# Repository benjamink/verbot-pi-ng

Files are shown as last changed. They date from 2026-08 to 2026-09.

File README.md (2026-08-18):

# verbot-pi-ng

Control a 1984 [Tomy Verbot](https://www.theoldrobots.com/verbot.html) toy robot
from a Raspberry Pi Zero 2 W, over an HTTP API, with speech output.

The original 1980s electronics are removed; the motor, gearbox, interrogation
switch bank and front keypad are all retained and driven directly from the Pi.

New here? [**Theory of operation**](docs/theory-of-operation.md) explains how
the gearbox works, what replaced the original electronics, how the software
drives it, and the API.

## Status

**Software complete and tested off-Pi; not yet run on the robot.**

The state machine, HTTP API, speech, keypad and both hardware adapters are
implemented with a passing test suite that needs no Raspberry Pi. What remains
is physical bring-up: wiring the MCP23017 to the front panel, and working
through the [bring-up checklist](docs/deployment.md#bring-up-checklist) to
verify switch polarity, button order and the measured motor speeds.

See [the implementation plan](docs/superpowers/plans/2026-08-11-verbot-pi-ng.md)
for the task breakdown and deferred phase 2 work.

## Features

- **HTTP API** (FastAPI) for every robot action, with OpenAPI docs at `/docs`
- **Speech output** via an I2S DAC and `espeak-ng`
- **Front-panel keypad** — the original eight buttons drive the robot directly,
  with no network required
- **Status LED** in the original panel position
- **Optional shutdown endpoint** — power the Pi down over HTTP, guarded by a
  token and off by default
- **Zeroconf/mDNS** service advertisement for discovery
- **Runs its full test suite off-Pi** — hardware sits behind protocols with
  in-memory fakes

## Hardware

- Tomy Verbot with working motor and gearbox
- Raspberry Pi Zero 2 W (64-bit Raspberry Pi OS, Trixie)
- DRV8833 dual motor driver carrier
- MAX98357A I2S DAC/amplifier + small **passive** speaker (4–8Ω)
- MCP23017 I2C GPIO expander (front-panel buttons + status LED)
- [Pimoroni OnOff SHIM](https://shop.pimoroni.com/products/onoff-shim)
- 5V USB power bank

Wiring, pin assignments and the reverse-engineered mechanical details are in
[`docs/hardware.md`](docs/hardware.md), and the full schematic is at
[`hardware/verbot-schematic.pdf`](hardware/verbot-schematic.pdf)
([SVG](hardware/verbot-schematic.svg)). For bench work,
[`hardware/wiring-map.html`](hardware/wiring-map.html) draws the same wiring in
colour, with the interrogation ribbon in its actual conductor colours.

## Development

Requires [uv](https://docs.astral.sh/uv/). No Raspberry Pi needed — the
hardware layer has fakes.

```bash
uv sync            # create .venv and install deps
uv run pytest      # run the test suite
uv run ruff check  # lint
```

## Running on the Pi

```bash
sudo apt install espeak-ng
uv sync --extra pi --frozen
VERBOT_USE_REAL_HARDWARE=true uv run verbot
```

Full instructions, including the required device tree overlays and the
bring-up checklist, are in [`docs/deployment.md`](docs/deployment.md).

## Credits

The hardware reverse-engineering this project depends on was done by
**Neil Davis** for [neildavis/verbot-pi](https://github.com/neildavis/verbot-pi).
This is an independent rewrite targeting different hardware, without the Google
Assistant integration. See [LICENSE](LICENSE).

## License

MIT

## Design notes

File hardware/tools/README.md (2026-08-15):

# Schematic generator

One-shot scaffolding that produced `../verbot.kicad_sch`.

Writing a 40-pin header plus six module blocks as raw S-expressions by hand is
impractical — every coordinate must land on the 1.27mm grid, and the file must
embed a full copy of every symbol it uses. This generator reads the geometry
out of the KiCad libraries so those numbers are derived rather than typed.

**The generated `.kicad_sch` is authoritative.** Once it has been opened and
edited in eeschema, do not re-run the generator over it — you would discard
those edits. It is kept here because it documents how the sheet was built and
would save real work if the pin map ever changed wholesale.

`selftest.py` is a standalone script, not a pytest module, even though the
rest of the repo uses pytest exclusively. Its checks read
`/usr/share/kicad/symbols`, which only exists on a machine with KiCad
installed; folding it into `tests/` would break the README's promise that
`uv run pytest` works on any machine with no special setup.

```bash
cd hardware/tools
python3 selftest.py            # check the geometry reader
python3 generate_schematic.py  # regenerate (destructive)
```

If you regenerate `verbot.kicad_sym` with `make_symbols.py`, run
`kicad-cli sym upgrade --force ../verbot.kicad_sym` afterwards. `make_symbols.py`
writes each pin's `(at ...)` on the same line as `(pin ...)`; `_PIN_RE` in
`kicadgen.py` requires the newline-before-`(at` layout that only the upgrade
pass produces, and without it `generate_schematic.py` fails with `KeyError:
'1'` trying to look up a pin number that was never parsed.

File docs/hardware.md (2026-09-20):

# Verbot Hardware Reference

> **Attribution:** The electro-mechanical analysis and the interrogation switch
> wiring table in this document were reverse-engineered by **Neil Davis** for
> [neildavis/verbot-pi](https://github.com/neildavis/verbot-pi) (MIT licensed),
> partly from [Tomy's patent US4717364A](https://patents.google.com/patent/US4717364A/en).
> They are reproduced here with thanks. The GPIO assignments are new to this
> project and differ from the original.

> 📐 **Schematic:** [`hardware/verbot-schematic.pdf`](../hardware/verbot-schematic.pdf)
> ([SVG](../hardware/verbot-schematic.svg)) — the full wiring on one sheet.
> Source: [`hardware/verbot.kicad_sch`](../hardware/verbot.kicad_sch) (KiCad 10).
> The GPIO table below and `src/verbot/config.py` remain the pin-map source of
> truth; the schematic reproduces them.

> 🎨 **Wiring map:** [`hardware/wiring-map.html`](../hardware/wiring-map.html)
> — the same wiring drawn in colour, with the interrogation ribbon rendered in
> its actual conductor colours. Easier to work from at the bench than the
> schematic; open it in a browser.

## Electro-mechanical operation

Verbot is driven by a **single bi-directional 3V DC motor** and a set of
planetary gears. Motor direction selects between two mutually exclusive modes:

| Polarity | Motor direction | Operating mode |
|---|---|---|
| Normal | Anti-clockwise  | Interrogation  |
| Reverse  | Clockwise | Action |

### Interrogation mode

The default on power-up. The motor turns a drum carrying 8 cams spaced equally
around its circumference. Each cam activates and then releases one of 8
normally-open switches in a fixed repeating sequence. Verbot performs no
visible movement in this mode — it is selecting which gear set is engaged.

The switches complete a circuit to ground, so their state is readable from
GPIO inputs.

### Action mode

Reversing the motor engages a clutch: the drum stops, leaving the last-selected
switch engaged, and a shaft inside the drum begins to turn. The planetary gear
set at the selected position performs its action, and continues until the motor
is reversed again.

The arm actions (`pick_up` / `put_down`) have mechanical **limit switches** in
series. When an arm reaches its travel limit the circuit breaks, which the
controller observes as the switch *releasing* while the action is running. That
is the signal to stop — without it the mechanism will strain against its stop.

### Putting it together

To perform action X: run the motor anti-clockwise until switch X activates,
then immediately reverse to clockwise. The gear set for X is now engaged and in
the correct position.

## Interrogation switch wiring

Nine-core ribbon cable from the gearbox switch bank to the original controller
board:

| Colour | Interrogation order | Action |
|---|---|---|
| White  | N/A | GND — common return for all switches |
| Purple | 1 | Stop |
| Red | 2 | Rotate right  |
| Yellow | 3 | Rotate left |
| Grey | 4 | Move forward  |
| Blue | 5 | Move backward |
| Brown  | 6 | Arms down / put down |
| Orange | 7 | Arms up / pick up |
| Green  | 8 | Talk |

## Power supply

- **3V DC** (orange +ve, black ground) from 2× 'C' cells drove the motor. The
  original board reversed its polarity; the DRV8833 does that job now.
- **6V DC** (red +ve, black ground) from 4× 'AA' cells fed the original control
  board. That board and supply are removed; a 5V USB power bank feeds the Pi.
- Both rails were switched by the board behind the front keypad panel, which
  also fed the red power LED in the panel's bottom-right corner.

Where the motor's supply comes from now, and why it is not the Pi, is in
[Powering the motor](#powering-the-motor).

> ⚠️ The eight front-panel keypad buttons share that board with the power
> switching. Before wiring them to the MCP23017, trace whether they are
> independent switches to a common rail or a matrix, and decide what takes over
> the power-switch role (most likely the OnOff SHIM alone). It may be cleanest
> to bypass the original PCB and solder to the switch contacts directly.

## Original keypad behaviour

Each of the eight red buttons corresponded 1:1 to one of the eight actions. In
the original toy you *held a button down while speaking* the command you wanted
associated with it, and an LED blinked during program mode. This project
re-uses the 1:1 mapping; the hold gesture is available for re-binding.

## GPIO assignments (this project)

Raspberry Pi Zero 2 W, 64-bit Raspberry Pi OS (Trixie). **Bold** = Verbot
interrogation switches, inputs with pull-ups, active low.

| BCM | Physical | Used by | Function |
|-----|---|---|---|
| 2 | 3 | I2C1 | SDA — MCP23017 |
| 3 | 5 | I2C1 | SCL — MCP23017 |
| 4 | 7 | OnOff SHIM | Shutdown |
| 6 | 31 | DRV8833 | nSLEEP (`EEP`) — high wakes the driver (output) |
| 7 | 26 | **Verbot** | SW Talk |
| 8 | 24 | **Verbot** | SW Pick up |
| 9 | 21 | **Verbot** | SW Forwards |
| 10  | 19 | **Verbot** | SW Rotate left |
| 11  | 23 | **Verbot** | SW Put down |
| 12  | 32 | DRV8833 | Motor `IN1` — kernel PWM0 |
| 13  | 33 | DRV8833 | Motor `IN2` — kernel PWM1 |
| 16  | 36 | DRV8833 | nFAULT (`ULT`) — active low, input with pull-up |
| 17  | 11 | **Verbot** | Ready signal — high once the API is serving (output). Reassigned from the OnOff SHIM's power button; this board has no SHIM fitted. If one is added later, move this to a free pin instead. |
| 18  | 12 | I2S DAC | BCLK |
| 19  | 35 | I2S DAC | LRCLK |
| 21  | 40 | I2S DAC | DIN |
| 22  | 15 | **Verbot** | SW Stop |
| 25  | 22 | **Verbot** | SW Reverse |
| 26  | 37 | **Verbot** | SW Rotate right |
| 27  | 13 | OnOff SHIM | LED |

Both PWM channels come from one overlay:
`dtoverlay=pwm-2chan,pin=12,func=4,pin2=13,func2=4`.

**Free:** BCM 5, 14, 15, 20, 23, 24.

### Count the I2S pins twice

The three I2S lines sit next to pins that fail silently when you are off by one:

| Intended | Header | Neighbour | What you get |
|---|---|---|---|
| BCLK | 12 | **14 = GND** | Bit clock grounded. Dead silence. |
| DIN | 40 | **38 = BCM 20, PCM_DIN** | Data on the input pin. Dead silence. |
| LRCLK | 35 | 33 = BCM 13 (`IN2`) | Word clock into the motor driver. |

None of these produce an error anywhere. The overlay still registers the card,
`aplay -l` still lists the MAX98357A, `pinctrl get 18-21` still reports `a0` on
all three, and `/proc/asound/card0/pcm0p/sub0/hw_params` still reads `RUNNING`
with the pointer advancing. The Pi is genuinely clocking valid I2S — it is just
not arriving. Every software check passes while the speaker stays silent.

If there is no sound, check continuity from the header pin to the breakout pad
**before** touching the overlay. `speaker-test -D plughw:0,0` returning 0 says
nothing about whether audio reached the amp.

Confirm the amp is alive with a meter instead: SD_MODE on the Adafruit board
sits at ~0.45 V (its 1 MΩ pull-up against the chip's 100 kΩ internal pulldown),
which the MAX98357A reads as enabled in (L+R)/2 mono. Below 0.16 V is shutdown.
That reading also means `no-sdmode` is correct for this board — SD_MODE is not
wired to a GPIO, so the `sdmode` overlay variant does nothing here except claim
BCM 4, which the OnOff SHIM needs.

## DRV8833 carrier wiring

The common 12-pin breakout (`IN1`–`IN4`, `OUT1`–`OUT4`, `VCC`, `GND`, `EEP`,
`ULT`). Only channel A is used; `IN3`/`IN4`/`OUT3`/`OUT4` are left unconnected.

| Carrier pin | Goes to | Notes |
|---|---|---|
| `VCC` | Motor supply | **Not a logic rail.** The chip runs its own 3.3V regulator off this, so whatever you apply is what the motor sees. |
| `GND` | Pi GND | Common ground with the Pi is required for the logic to work. |
| `IN1` | BCM 12 | PWM0 |
| `IN2` | BCM 13 | PWM1 |
| `OUT1`/`OUT2` | Verbot motor | Polarity decides which sign is interrogation; swap if reversed. |
| `EEP` | BCM 6 | nSLEEP. The `J1` solder jumper ties this to `VCC` — check it with a meter. If it is bridged, set `VERBOT_MOTOR_SLEEP_PIN` to `null` and leave BCM 6 free. |
| `ULT` | BCM 16 | nFAULT, open-drain. Relies on the Pi's internal pull-up. |

Feeding `VCC` from 5V means the 3V motor sees 5V at full duty — cap
`VERBOT_ACTION_SPEED` accordingly rather than running it at ±100. Do **not**
feed `VCC` from the Pi's 3V3 pin to get a nominal 3V: that rail comes off the
PMIC and cannot supply a stalled motor.

There is no MODE pin. Unlike the DRV8835 this part has no PHASE/ENABLE mode,
which is why direction costs a second PWM channel rather than one GPIO.

### Powering the motor

**The Pi does not power the motor.** Two separate paths run through the carrier,
and confusing them is the usual source of "a GPIO can't supply that much
current":

- **Signal path** — `IN1`, `IN2` and `EEP` are high-impedance CMOS inputs
  drawing microamps. The Pi only says *which switches to close*. A GPIO sources
  around 16 mA, and the whole header perhaps 50 mA — orders of magnitude short
  of motor current, and it never has to supply it.
- **Power path** — motor current flows from `VCC`, through the H-bridge
  MOSFETs, out `OUT1`/`OUT2`, through the motor and back to `GND`. It never
  touches a GPIO.

That is why `VCC` is not a logic rail, and why the common ground still matters:
almost no current flows on that wire, but without a shared reference the carrier
cannot interpret the Pi's logic levels at all.

**Feed `VCC` from the power bank directly, not from the Pi's 5V header pin.**
The header pin is the USB input rail passed straight through, so it does work
electrically. But the motor then shares a supply with the Pi, and a stall or a
direction reversal can drag that rail down far enough to drop the Wi-Fi or reset
the board — and if the OnOff SHIM is inline, the motor current runs through the
SHIM as well. A 3V motor from 2× 'C' cells can pull on the order of an amp
stalled, which is not something to route through header pins.

Fit **100–470 µF** of electrolytic bulk capacitance across `VCC`/`GND` close to
the carrier. A direction reversal switches the full motor current in one step,
and without local storage that transient is taken straight out of the shared
supply.

| Pin | Feed from | Why |
|-----|---|-----|
| `VCC` | Power bank 5V | Not the Pi's 3V3 — that rail is off the PMIC and cannot supply a stalled motor |
| `GND` | Common with the Pi | Shared reference for the logic; carries no significant current |

Because `VCC` is 5V and the motor is a 3V part, cap `VERBOT_ACTION_SPEED` rather
than running ±100 — the PWM duty cycle is what keeps the average voltage near
the motor's rating.

### Notable changes from the original project

- **DRV8833 instead of a DRV8835**, driven as IN/IN on two kernel PWM channels
  (BCM 12 and 13) rather than one PWM plus a direction pin. Its `nSLEEP` and
  `nFAULT` lines are wired up; nothing reads the fault line yet.
- **Motor PWM is kernel-managed**, not pigpio. pigpio needs the PCM peripheral
  for DMA timing to leave hardware PWM available; the I2S DAC needs PCM too.
  Kernel PWM sidesteps that conflict entirely — the original project had to
  abandon hardware PWM for exactly this reason.
- **No AIY Voice Bonnet**, freeing BCM 14, 15, 16, 20, 23.
- Front-panel buttons and status LED hang off an **MCP23017** rather than
  consuming the last eight free GPIOs.

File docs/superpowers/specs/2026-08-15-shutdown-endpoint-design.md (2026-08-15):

# Token-guarded shutdown endpoint — design

**Date:** 2026-08-15
**Status:** approved, ready for implementation

## Goal

Let the robot be powered down cleanly over HTTP, so the Pi can be shut down
without SSH and without the Pimoroni OnOff SHIM.

## Why

The OnOff SHIM provides the soft power switch. It has not arrived yet, and
pulling USB power without a clean shutdown risks SD card corruption. `POST
/stop` sounds like it would help but does not — it runs a mechanical
interrogation to find the stop cam and has nothing to do with system power.

This endpoint stays useful after the SHIM is wired (shutting down from a phone
without walking to the robot), but it is deliberately small: the SHIM is the
real answer, and this should not grow into a general remote-administration
surface.

## Security context

The API has **no authentication**, binds `0.0.0.0:8080`, and advertises itself
over mDNS. Anything on the LAN can discover the robot and drive it. That is an
accepted trade-off for the existing endpoints, where the worst case is someone
waving the robot's arms.

Remote poweroff is a different proposition, so this endpoint is opt-in and
separately authenticated rather than inheriting the open surface.

## Deliverables

| File | Change |
|---|---|
| `src/verbot/config.py` | add `shutdown_token: str \| None = None` |
| `src/verbot/hardware/protocols.py` | add `SystemPower` protocol |
| `src/verbot/hardware/system_power.py` | new — `SubprocessPower` adapter |
| `src/verbot/hardware/fakes.py` | add `FakePower` |
| `src/verbot/main_support.py` | add `build_power(settings)` |
| `src/verbot/controller.py` | add `Controller.halt()` |
| `src/verbot/api.py` | widen `create_app`, add the route |
| `src/verbot/__main__.py` | pass `settings` and `power` to `create_app` |
| `tests/test_api.py` | update fixture, add endpoint tests |
| `tests/test_controller.py` | add `halt()` test |
| `tests/test_main.py` | add `build_power` test |
| `docs/deployment.md` | sudoers rule, token generation, caveats |
| `README.md` | one line in Features |

## The off switch

`Settings` gains:

```python
shutdown_token: str | None = None
```

When it is `None`, **the route is never registered**. Not registered-then-403:
genuinely absent, so it is also missing from `/docs` and `/openapi.json` and
the capability is not advertised to anyone scanning. The existing API surface
is byte-identical unless the operator opts in.

## SystemPower protocol

Follows the established `MotorDriver` / `SpeechEngine` / `Keypad` pattern, so
the suite keeps running off-Pi with no hardware and no root.

```python
# protocols.py
class SystemPower(Protocol):
    async def shutdown(self) -> None:
        """Power the machine off. Returns once the request is issued."""
```

`hardware/system_power.py` holds `SubprocessPower`, which shells out via
`asyncio.create_subprocess_exec`, mirroring how `EspeakEngine` already invokes
`espeak-ng`. `fakes.py` holds `FakePower`, which records `shutdown_called`.

`main_support.build_power(settings)` mirrors `build_hardware` and
`build_keypad`: **it returns `FakePower` whenever `use_real_hardware` is
false.** This is a safety property, not a convenience one — without it, running
the dev server on a laptop with a token configured would power off the laptop.

## The endpoint

```
POST /system/shutdown
  X-Verbot-Token: <token>

  202 { "status": "shutting down" }
  401 missing or incorrect token
  404 endpoint not configured
```

- The token is compared with `secrets.compare_digest`, so comparison is
  constant-time. A missing header short-circuits to a failure rather than being
  passed to `compare_digest`, which rejects `None`.
- On success the handler halts the motor, then schedules the poweroff as a
  FastAPI `BackgroundTask` so the 202 reaches the client before the machine
  dies.
- Returns 202 rather than 200: the shutdown has been accepted, not completed.

### Wiring

`create_app` widens to take the two new dependencies explicitly, rather than
reaching for globals:

```python
def create_app(
    controller: Controller,
    speech: SpeechEngine,
    settings: Settings,
    power: SystemPower,
) -> FastAPI:
```

Both new parameters are required. There are only two call sites —
`src/verbot/__main__.py:49` and the `client_rig` fixture in
`tests/test_api.py:16` — so widening is cheap, and a default would let a caller
silently get an app with no shutdown route when they meant to configure one.

`build_app` calls `build_power(settings)` alongside the existing
`build_hardware` and `build_keypad`, and passes both `settings` and `power`
through.

### Controller.halt()

A new method — cancel the pending timeout, then `set_speed_percent(0)`.

Strictly this is redundant: `poweroff` causes systemd to SIGTERM the unit,
which runs the FastAPI lifespan teardown, which already calls
`controller.close()` and stops the motor. Two reasons to do it explicitly
anyway:

1. That teardown is a few hundred milliseconds away, and the robot is driving
   for all of them.
2. If the sudoers rule is missing or wrong, `poweroff` fails silently and the
   motor would otherwise keep running indefinitely.

"Shutdown stops the robot" is the least surprising behaviour.

This is **not** `Action.STOP`. That runs a mechanical interrogation to find the
stop cam — the opposite of what is wanted when powering down.

## Deployment

The unit runs as an unprivileged `$USER`, so `poweroff` needs one narrow grant:

```
# /etc/sudoers.d/verbot-poweroff   (mode 0440, validate with visudo -c)
<user> ALL=(root) NOPASSWD: /usr/sbin/poweroff
```

Scoped to exactly that binary — not `NOPASSWD: ALL`. Confirm the real path with
`command -v poweroff` first: `/usr/sbin` on Trixie, `/sbin` on older images. A
wrong path fails closed.

Polkit is not an alternative: a systemd service has no seat or login session,
so the usual "a local user may power off without sudo" path does not apply.

`docs/deployment.md` documents the sudoers rule, token generation
(`openssl rand -hex 32`), and placing the token in `.env` beside
`VERBOT_USE_REAL_HARDWARE`. It also records that the token travels as a
plaintext header over unencrypted HTTP — acceptable on a home LAN, worth
knowing before exposing this more widely.

## Testing

TDD throughout, following the existing `client_rig` fixture pattern in
`tests/test_api.py`, plus a second fixture that builds an app with a token set.

| Test | Asserts |
|---|---|
| token unset | 404, and the path is absent from `/openapi.json` |
| token set, no header | 401, `shutdown_called` False |
| token set, wrong token | 401, `shutdown_called` False |
| token set, correct token | 202, `shutdown_called` True, motor speed 0 |
| `build_power` off-Pi | returns `FakePower` when `use_real_hardware` is false |
| `Controller.halt()` | sets speed 0 and cancels the pending timeout |

The negative cases carry more weight than the positive one: "wrong token still
powers off the robot" is the failure that costs something, and it is exactly
what a happy-path-only suite ships.

No new dependencies — `secrets` is stdlib and `BackgroundTasks` is already part
of FastAPI. The suite must keep running off-Pi with no hardware and no root.

## Out of scope

- Reboot. Shutdown is the need; a second route can be added later if wanted.
- Any other system or administration endpoints.
- Authentication for the existing endpoints. That is a separate decision, and
  bundling it here would hide it.
- HTTPS or transport security.

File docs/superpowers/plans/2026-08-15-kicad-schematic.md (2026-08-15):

# KiCad Wiring Schematic Implementation Plan

> **For agentic workers:** REQUIRED SUB-SKILL: Use superpowers:subagent-driven-development (recommended) or superpowers:executing-plans to implement this plan task-by-task. Steps use checkbox (`- [ ]`) syntax for tracking.

**Goal:** Produce a single-sheet A3 KiCad schematic documenting how every part of the robot wires to the Raspberry Pi Zero 2 W, ERC-clean and exported to committed PDF/SVG.

**Architecture:** A one-shot Python generator assembles the `.kicad_sch` S-expression, reading symbol geometry directly out of the KiCad stock libraries so pin coordinates are never hand-computed. Module blocks that have no stock equivalent live in a project symbol library. Once generated and committed, the `.kicad_sch` is the authoritative artifact and is edited in eeschema like any normal project — the generator is scaffolding, not a maintained pipeline.

**Tech Stack:** KiCad 10.0.5 (`kicad-cli`), Python 3.13 stdlib only (no new project dependencies).

Spec: `docs/superpowers/specs/2026-08-15-kicad-schematic-design.md`

## Global Constraints

- Schematic file format: `(version 20260306)`, `(generator_version "10.0")`. Symbol library format: `(version 20251024)`.
- **Every coordinate must be an exact multiple of 1.27mm.** Off-grid endpoints produce `endpoint_off_grid` ERC warnings. This was verified empirically — it is the single most common failure mode when writing these files by hand.
- Paper size: `A3` (420 × 297 mm).
- `lib_symbols` must embed a full copy of every symbol used, re-keyed from `(symbol "NAME"` to `(symbol "Lib:NAME"`.
- Every externally-driven power net (`+5V`, `+3V3`, `GND`) needs a `power:PWR_FLAG` connected to it, or ERC raises `power_pin_not_driven` as an **error**.
- Every `no_connect` flag must sit exactly on a pin coordinate, or ERC raises `no_connect_dangling` as a warning.
- **Line breaks inside a `text_note` body must be written `\n` in the Python source** (a literal backslash-n), so the emitted file carries the two-character `\n` escape KiCad expects inside a quoted string. A real newline character inside a quoted S-expression string makes the file unparseable — `kicad-cli` reports `Failed to load schematic`, verified empirically. This applies only to string *contents*; joins that separate top-level blocks (`lib_cache`, `BODY`) need real newlines.
- Acceptance gate for every task from Task 3 onward: `kicad-cli sch erc --severity-all --exit-code-violations hardware/verbot.kicad_sch` exits 0 and reports `0 Errors 0 Warnings`.
- No changes to any file under `src/` or `tests/`. This task adds no Python runtime dependencies.
- Pin assignments come from `src/verbot/config.py` and `docs/hardware.md`. Do not invent any.

## File Structure

| File | Responsibility |
|---|---|
| `hardware/verbot.kicad_pro` | KiCad project file |
| `hardware/verbot.kicad_sch` | The single A3 sheet (generated once, then hand-edited) |
| `hardware/verbot.kicad_sym` | Project symbol library: 5 module block symbols |
| `hardware/sym-lib-table` | Registers `verbot.kicad_sym` as nickname `verbot` |
| `hardware/tools/kicadgen.py` | Generator library: S-expression emitters + symbol geometry reader |
| `hardware/tools/generate_schematic.py` | One-shot script that lays out the sheet |
| `hardware/tools/README.md` | Explains that the generator is scaffolding and the `.kicad_sch` is authoritative |
| `hardware/verbot-schematic.pdf` | Exported, committed |
| `hardware/verbot-schematic.svg` | Exported, committed |
| `docs/hardware.md` | Modified: link to the PDF near the top |

---

### Task 1: Project scaffolding and the symbol-geometry reader

**Files:**
- Create: `hardware/verbot.kicad_pro`
- Create: `hardware/sym-lib-table`
- Create: `hardware/tools/kicadgen.py`
- Create: `hardware/tools/README.md`
- Test: `hardware/tools/selftest.py`

**Interfaces:**
- Consumes: nothing
- Produces: `kicadgen.extract_symbol(lib, name) -> str`, `kicadgen.pin_positions(lib, name) -> dict[str, Pin]`, `kicadgen.lib_symbol(lib, name) -> str`, `kicadgen.on_grid(v) -> float`, `kicadgen.assert_grid(*pts) -> None`, `kicadgen.uid() -> str`, and the dataclass `Pin(x: float, y: float, rot: int, name: str)`. Later tasks import all of these.

- [ ] **Step 1: Write the failing self-test**

`hardware/tools/selftest.py`:

```python
"""Self-checks for the schematic generator. Run: python3 hardware/tools/selftest.py"""

import sys

from kicadgen import Pin, assert_grid, extract_symbol, lib_symbol, on_grid, pin_positions

def test_extract_symbol_is_balanced():
    block = extract_symbol("Device", "R")
    assert block.startswith('(symbol "R"'), block[:40]
    assert block.count("(") == block.count(")"), "unbalanced parens"

def test_lib_symbol_is_rekeyed():
    block = lib_symbol("Device", "R")
    assert block.startswith('(symbol "Device:R"'), block[:40]

def test_pin_positions_reads_all_pi_header_pins():
    pins = pin_positions("Connector", "Raspberry_Pi_2_3")
    assert len(pins) == 40, len(pins)
    assert pins["1"] == Pin(5.08, 33.02, 270, "3V3")
    assert pins["32"].x == 20.32 and pins["32"].y == -17.78

def test_pi_header_pins_are_all_on_grid():
    pins = pin_positions("Connector", "Raspberry_Pi_2_3")
    off = [n for n, p in pins.items() if on_grid(p.x) != p.x or on_grid(p.y) != p.y]
    assert off == [], off

def test_assert_grid_rejects_off_grid_points():
    assert_grid((101.6, 97.79))
    try:
        assert_grid((100.0, 100.0))
    except ValueError:
        return
    raise AssertionError("assert_grid accepted an off-grid point")

if __name__ == "__main__":
    failures = 0
    for name, fn in sorted(globals().items()):
        if name.startswith("test_"):
            try:
                fn()
                print(f"PASS {name}")
            except Exception as exc:
                failures += 1
                print(f"FAIL {name}: {exc}")
    sys.exit(1 if failures else 0)
```

- [ ] **Step 2: Run it to verify it fails**

Run: `cd hardware/tools && python3 selftest.py`
Expected: `ModuleNotFoundError: No module named 'kicadgen'`

- [ ] **Step 3: Write `hardware/tools/kicadgen.py`**

```python
"""S-expression emitters and KiCad symbol-geometry reader.

One-shot scaffolding for generating hardware/verbot.kicad_sch. Once that file
exists and has been opened in eeschema, IT is authoritative - see README.md.

Everything here targets KiCad 10 (schematic format 20260306). The 1.27mm grid
is enforced rather than assumed: off-grid endpoints are the most common cause
of ERC endpoint_off_grid warnings in hand-built files.
"""

import re
import uuid
from dataclasses import dataclass

SYMBOL_DIR = "/usr/share/kicad/symbols"
GRID = 1.27

@dataclass(frozen=True)
class Pin:
    x: float
    y: float
    rot: int
    name: str

def uid() -> str:
    return str(uuid.uuid4())

def on_grid(value: float) -> float:
    """Snap to the 1.27mm connection grid, rounded to 2dp for the file."""
    return round(round(value / GRID) * GRID, 2)

def assert_grid(*points: tuple[float, float]) -> None:
    """Raise if any point is off the connection grid.

    Called on every coordinate before it reaches the file. Catching it here
    gives a traceback pointing at the offending placement; catching it in ERC
    gives a millimetre position and a hunt.
    """
    for x, y in points:
        for axis, value in (("x", x), ("y", y)):
            if abs(value / GRID - round(value / GRID)) > 1e-6:
                raise ValueError(f"off-grid {axis}={value} (grid {GRID})")

def _library_path(lib: str) -> str:
    return f"{SYMBOL_DIR}/{lib}.kicad_sym"

def extract_symbol(lib: str, name: str) -> str:
    """Return the complete top-level (symbol "NAME" ...) block from a library.

    Paren-matching rather than regex: symbol bodies nest several levels deep
    and contain parentheses inside quoted strings.
    """
    text = open(_library_path(lib)).read()
    start = text.index(f'(symbol "{name}"')
    depth = 0
    in_string = False
    i = start
    while i < len(text):
        char = text[i]
        if in_string:
            if char == "\\":
                i += 2
                continue
            if char == '"':
                in_string = False
        elif char == '"':
            in_string = True
        elif char == "(":
            depth += 1
        elif char == ")":
            depth -= 1
            if depth == 0:
                return text[start : i + 1]
        i += 1
    raise ValueError(f"unbalanced s-expression for {lib}:{name}")

def lib_symbol(lib: str, name: str) -> str:
    """The symbol block re-keyed to the "Lib:Name" form lib_symbols expects."""
    block = extract_symbol(lib, name)
    return block.replace(f'(symbol "{name}"', f'(symbol "{lib}:{name}"', 1)

_PIN_RE = re.compile(
    r'\(pin \w+ \w+\s*\n\s*\(at ([-\d.]+) ([-\d.]+) (\d+)\)'
    r'.*?\(name "([^"]*)".*?\(number "([^"]+)"',
    re.S,
)

def pin_positions(lib: str, name: str) -> dict[str, Pin]:
    """Map pin number -> Pin, in symbol-local coordinates.

    Symbol Y is inverted relative to schematic Y, so a symbol pin at +y appears
    at (origin_y - y) once placed. absolute_pin() does that conversion.
    """
    block = extract_symbol(lib, name)
    pins: dict[str, Pin] = {}
    for match in _PIN_RE.finditer(block):
        x, y, rot, pin_name, number = match.groups()
        pins[number] = Pin(float(x), float(y), int(rot), pin_name)
    return pins

def absolute_pin(origin: tuple[float, float], pin: Pin) -> tuple[float, float]:
    """Schematic coordinates of a pin on a symbol placed at origin, rotation 0."""
    return (round(origin[0] + pin.x, 2), round(origin[1] - pin.y, 2))
```

- [ ] **Step 4: Run the self-test to verify it passes**

Run: `cd hardware/tools && python3 selftest.py`
Expected: five `PASS` lines, exit 0.

If `test_pin_positions_reads_all_pi_header_pins` fails on the `Pin(5.08, 33.02, 270, "3V3")` comparison, print `pins["1"]` and correct the expected pin *name* only — the coordinates are verified correct. Stock library pin naming can vary between KiCad point releases.

- [ ] **Step 5: Write `hardware/verbot.kicad_pro`**

```json
{
  "board": {},
  "boards": [],
  "libraries": {
    "pinned_footprint_libs": [],
    "pinned_symbol_libs": []
  },
  "meta": {
    "filename": "verbot.kicad_pro",
    "version": 3
  },
  "net_settings": {
    "classes": [
      {
        "bus_width": 12,
        "clearance": 0.2,
        "name": "Default",
        "track_width": 0.2,
        "wire_width": 6
      }
    ]
  },
  "schematic": {
    "annotate_start_num": 0,
    "drawing": {
      "default_line_thickness": 6.0,
      "default_text_size": 50.0,
      "intersheets_ref_show": false
    },
    "legacy_lib_dir": "",
    "legacy_lib_list": []
  },
  "sheets": [],
  "text_variables": {}
}
```

- [ ] **Step 6: Write `hardware/sym-lib-table`**

```
(sym_lib_table
  (version 7)
  (lib (name "verbot")(type "KiCad")(uri "${KIPRJMOD}/verbot.kicad_sym")(options "")(descr "verbot-pi-ng module block symbols"))
)
```

- [ ] **Step 7: Write `hardware/tools/README.md`**

```markdown
# Schematic generator

One-shot scaffolding that produced `../verbot.kicad_sch`.

Writing a 40-pin header plus six module blocks as raw S-expressions by hand is
impractical — every coordinate must land on the 1.27mm grid, and the file must
embed a full copy of every symbol it uses. This generator reads the geometry
out of the KiCad libraries so those numbers are derived rather than typed.

**The generated `.kicad_sch` is authoritative.** Once it has been opened and
edited in eeschema, do not re-run the generator over it — you would discard
those edits. It is kept here because it documents how the sheet was built and
would save real work if the pin map ever changed wholesale.

```bash
cd hardware/tools
python3 selftest.py            # check the geometry reader
python3 generate_schematic.py  # regenerate (destructive)
```
```

- [ ] **Step 8: Commit**

```bash
git add hardware/
git commit -m "feat(hardware): KiCad project scaffolding and symbol geometry reader"
```

---

### Task 2: Project symbol library

**Files:**
- Create: `hardware/verbot.kicad_sym`
- Create: `hardware/tools/make_symbols.py`
- Modify: `hardware/tools/selftest.py` (add symbol library checks)

**Interfaces:**
- Consumes: `kicadgen.pin_positions`, `kicadgen.on_grid`
- Produces: library `verbot` containing symbols `DRV8833_Carrier`, `MAX98357A_Breakout`, `MCP23017_Breakout`, `OnOff_SHIM`, `Verbot_Gearbox`. Later tasks reference these as `verbot:NAME`.

Each symbol is a rectangle with pins on a 2.54mm pitch, pin names matching the board's silkscreen. All pins use `passive` electrical type except where noted, so ERC does not invent conflicts between two module blocks wired together.

- [ ] **Step 1: Write `hardware/tools/make_symbols.py`**

```python
"""Generate hardware/verbot.kicad_sym - block symbols for the bought modules.

Pin names match what is silkscreened on each board, so the schematic reads the
same as the part in your hand. Electrical types are deliberately conservative:
module pins are 'passive' unless the module actively drives them, which keeps
ERC focused on real wiring mistakes rather than type-conflict noise.
"""

from kicadgen import assert_grid

PITCH = 2.54

def rect_symbol(name, description, left_pins, right_pins, width=50.8):
    """Build a rectangular block symbol.

    left_pins/right_pins are lists of (number, name, etype). Pins are laid out
    top-down on 2.54mm pitch; the body grows to fit the taller side.
    """
    rows = max(len(left_pins), len(right_pins))
    height = (rows + 1) * PITCH
    top = height / 2
    half_w = width / 2
    assert_grid((half_w, top))

    out = [
        f'\t(symbol "{name}"',
        "\t\t(exclude_from_sim no)(in_bom yes)(on_board yes)",
        f'\t\t(property "Reference" "U" (at 0 {top + PITCH} 0)',
        "\t\t\t(effects (font (size 1.27 1.27))))",
        f'\t\t(property "Value" "{name}" (at 0 {-top - PITCH} 0)',
        "\t\t\t(effects (font (size 1.27 1.27))))",
        '\t\t(property "Footprint" "" (at 0 0 0)',
        "\t\t\t(effects (font (size 1.27 1.27)) (hide yes)))",
        '\t\t(property "Datasheet" "" (at 0 0 0)',
        "\t\t\t(effects (font (size 1.27 1.27)) (hide yes)))",
        f'\t\t(property "Description" "{description}" (at 0 0 0)',
        "\t\t\t(effects (font (size 1.27 1.27)) (hide yes)))",
        f'\t\t(symbol "{name}_0_1"',
        f"\t\t\t(rectangle (start {-half_w} {top}) (end {half_w} {-top})",
        "\t\t\t\t(stroke (width 0.254) (type default))",
        "\t\t\t\t(fill (type background)))",
        "\t\t)",
        f'\t\t(symbol "{name}_1_1"',
    ]

    for side, pins in (("left", left_pins), ("right", right_pins)):
        for index, (number, pin_name, etype) in enumerate(pins):
            y = top - (index + 1) * PITCH
            if side == "left":
                x, rot = -half_w - PITCH, 0
            else:
                x, rot = half_w + PITCH, 180
            assert_grid((x, y))
            out += [
                f"\t\t\t(pin {etype} line (at {x} {y} {rot}) (length {PITCH})",
                f'\t\t\t\t(name "{pin_name}" (effects (font (size 1.27 1.27))))',
                f'\t\t\t\t(number "{number}" (effects (font (size 1.27 1.27))))',
                "\t\t\t)",
            ]
    out += ["\t\t)", "\t)"]
    return "\n".join(out)

def numbered(names, etype="passive", start=1):
    return [(str(i + start), n, etype) for i, n in enumerate(names)]

DRV8833 = rect_symbol(
    "DRV8833_Carrier",
    "DRV8833 dual H-bridge carrier board (channel A used)",
    numbered(["VCC", "GND", "EEP", "ULT", "IN1", "IN2"]),
    numbered(["OUT1", "OUT2", "IN3", "IN4", "OUT3", "OUT4"], start=7),
)

MAX98357A = rect_symbol(
    "MAX98357A_Breakout",
    "MAX98357A I2S DAC / class-D amplifier breakout",
    numbered(["VIN", "GND", "SD", "GAIN"]),
    numbered(["DIN", "BCLK", "LRC", "+", "-"], start=5),
)

MCP23017 = rect_symbol(
    "MCP23017_Breakout",
    "MCP23017 16-bit I2C GPIO expander breakout",
    numbered(
        ["VDD", "VSS", "SDA", "SCL", "RESET", "A0", "A1", "A2", "INTA", "INTB"]
    ),
    numbered([f"GPA{i}" for i in range(8)] + [f"GPB{i}" for i in range(8)], start=11),
    width=63.5,
)

ONOFF = rect_symbol(
    "OnOff_SHIM",
    "Pimoroni OnOff SHIM - soft power switch for Raspberry Pi",
    numbered(["USB_5V_IN", "GND"]),
    numbered(["5V_OUT", "BTN", "LED", "POWEROFF"], start=3),
    width=45.72,
)

GEARBOX = rect_symbol(
    "Verbot_Gearbox",
    "Tomy Verbot gearbox: 9-core interrogation switch harness and motor",
    numbered(
        [
            "WHITE_GND",
            "PURPLE",
            "RED",
            "YELLOW",
            "GREY",
            "BLUE",
            "BROWN",
            "ORANGE",
            "GREEN",
        ]
    ),
    numbered(["MOTOR_A", "MOTOR_B"], start=10),
    width=63.5,
)

LIBRARY = f"""(kicad_symbol_lib
	(version 20251024)
	(generator "verbot-make-symbols")
	(generator_version "10.0")
{DRV8833}
{MAX98357A}
{MCP23017}
{ONOFF}
{GEARBOX}
)
"""

if __name__ == "__main__":
    with open("../verbot.kicad_sym", "w") as handle:
        handle.write(LIBRARY)
    print("wrote hardware/verbot.kicad_sym")
```

- [ ] **Step 2: Generate the library**

Run: `cd hardware/tools && python3 make_symbols.py`
Expected: `wrote hardware/verbot.kicad_sym`

- [ ] **Step 3: Verify KiCad parses it**

Run: `kicad-cli sym upgrade --force hardware/verbot.kicad_sym`
Expected: no parse error. A message that the library is already at the current version is also acceptable.

If it reports a syntax error, the message names a line — the usual cause is a `(pin ...)` block outside the `_1_1` sub-symbol.

- [ ] **Step 4: Verify every symbol renders**

Run:
```bash
mkdir -p /tmp/symcheck && kicad-cli sym export svg -o /tmp/symcheck hardware/verbot.kicad_sym && ls /tmp/symcheck
```
Expected: five SVG files, one per symbol.

- [ ] **Step 5: Add library checks to the self-test**

Append to `hardware/tools/selftest.py`, above the `__main__` block:

```python
def test_project_library_has_all_five_symbols():
    text = open("../verbot.kicad_sym").read()
    for name in (
        "DRV8833_Carrier",
        "MAX98357A_Breakout",
        "MCP23017_Breakout",
        "OnOff_SHIM",
        "Verbot_Gearbox",
    ):
        assert f'(symbol "{name}"' in text, f"missing symbol {name}"

def test_project_library_is_balanced():
    text = open("../verbot.kicad_sym").read()
    assert text.count("(") == text.count(")"), "unbalanced parens"

def test_gearbox_names_pins_by_wire_colour():
    text = open("../verbot.kicad_sym").read()
    for colour in ("PURPLE", "RED", "YELLOW", "GREY", "BLUE", "BROWN", "ORANGE", "GREEN"):
        assert f'(name "{colour}"' in text, f"missing gearbox pin {colour}"
```

- [ ] **Step 6: Run the self-test**

Run: `cd hardware/tools && python3 selftest.py`
Expected: eight `PASS` lines, exit 0.

- [ ] **Step 7: Commit**

```bash
git add hardware/
git commit -m "feat(hardware): block symbols for DRV8833, MAX98357A, MCP23017, OnOff SHIM, gearbox"
```

---

### Task 3: Sheet generator and the power section

**Files:**
- Create: `hardware/tools/generate_schematic.py`
- Create: `hardware/verbot.kicad_sch` (generated)

**Interfaces:**
- Consumes: everything from `kicadgen`; the `verbot` library from Task 2.
- Produces: `generate_schematic.py` module-level helpers `sym()`, `wire()`, `label()`, `nc()`, `text_note()`, the `BODY` list, and the constant `PI_AT` (Pi header origin). Tasks 4–8 append to `BODY` and call these helpers with identical signatures.

This task builds the generator skeleton, places the Pi header, and wires the power tree. Nothing else is on the sheet yet.

- [ ] **Step 1: Write the generator skeleton — `hardware/tools/generate_schematic.py`**

Write this file complete, in one go. Steps 2 onward only append sections to it.

```python
"""Lay out hardware/verbot.kicad_sch.

One-shot scaffolding - see README.md. The generated file is authoritative once
eeschema has touched it.

Layout is a single A3 sheet: Pi header centred, module blocks around it.
Signals travel by net label off short pin stubs rather than long routed wires,
which is the readable convention for a 40-pin part and keeps this file
manageable.
"""

from kicadgen import (
    Pin,
    absolute_pin,
    assert_grid,
    lib_symbol,
    pin_positions,
    uid,
)

ROOT_UUID = uid()
PROJECT = "verbot"

# Every symbol placed on the sheet: (lib, name). Drives the lib_symbols cache.
USED_SYMBOLS: list[tuple[str, str]] = []

BODY: list[str] = []

STUB = 3.81  # 3 * 1.27 - stub length from a pin to its net label

def use(lib: str, name: str) -> str:
    if (lib, name) not in USED_SYMBOLS:
        USED_SYMBOLS.append((lib, name))
    return f"{lib}:{name}"

def sym(lib, name, ref, value, at, rot=0, hide_value=False):
    """Place a symbol instance and return its pin-position lookup."""
    lib_id = use(lib, name)
    pins = pin_positions(lib, name) if lib != "verbot" else _project_pins(name)
    x, y = at
    assert_grid(at)
    value_effects = "(hide yes)" if hide_value else ""
    pin_blocks = "\n".join(f'\t\t(pin "{n}" (uuid "{uid()}"))' for n in pins)
    BODY.append(
        f"""	(symbol
		(lib_id "{lib_id}")
		(at {x} {y} {rot})
		(unit 1)
		(exclude_from_sim no)
		(in_bom yes)
		(on_board yes)
		(dnp no)
		(uuid "{uid()}")
		(property "Reference" "{ref}" (at {x} {y - 2.54} 0)
			(effects (font (size 1.27 1.27)) (justify left)))
		(property "Value" "{value}" (at {x} {y + 2.54} 0)
			(effects (font (size 1.27 1.27)) (justify left) {value_effects}))
{pin_blocks}
		(instances
			(project "{PROJECT}"
				(path "/{ROOT_UUID}" (reference "{ref}") (unit 1))))
	)"""
    )
    return {number: absolute_pin(at, pin) for number, pin in pins.items()}

def _project_pins(name: str) -> dict[str, Pin]:
    """pin_positions() for the project library, which is not in SYMBOL_DIR."""
    import kicadgen

    original = kicadgen.SYMBOL_DIR
    kicadgen.SYMBOL_DIR = ".."
    try:
        return kicadgen.pin_positions("verbot", name)
    finally:
        kicadgen.SYMBOL_DIR = original

def wire(start, end):
    assert_grid(start, end)
    BODY.append(
        f"""	(wire (pts (xy {start[0]} {start[1]}) (xy {end[0]} {end[1]}))
		(stroke (width 0) (type default)) (uuid "{uid()}"))"""
    )

def label(text, at, rot=0):
    assert_grid(at)
    BODY.append(
        f"""	(label "{text}" (at {at[0]} {at[1]} {rot})
		(effects (font (size 1.27 1.27)) (justify left bottom)) (uuid "{uid()}"))"""
    )

def nc(at):
    """No-connect flag. Must sit exactly on a pin or ERC flags it as dangling."""
    assert_grid(at)
    BODY.append(f'	(no_connect (at {at[0]} {at[1]}) (uuid "{uid()}"))')

def text_note(body, at, size=1.27):
    BODY.append(
        f"""	(text "{body}" (at {at[0]} {at[1]} 0)
		(effects (font (size {size} {size})) (justify left top)) (uuid "{uid()}"))"""
    )

def stub_label(pin_xy, net, direction):
    """Draw a short stub off a pin and label it. direction: 'L' or 'R'."""
    dx = -STUB if direction == "L" else STUB
    end = (round(pin_xy[0] + dx, 2), pin_xy[1])
    wire(pin_xy, end)
    label(net, end)

def _lib_symbol_any(lib, name):
    """lib_symbol() that also resolves the project library at ../verbot.kicad_sym."""
    import kicadgen

    if lib != "verbot":
        return lib_symbol(lib, name)
    original = kicadgen.SYMBOL_DIR
    kicadgen.SYMBOL_DIR = ".."
    try:
        return kicadgen.lib_symbol(lib, name)
    finally:
        kicadgen.SYMBOL_DIR = original

# --------------------------------------------------------------------------
# Power tree
# --------------------------------------------------------------------------

PI_AT = (215.9, 148.59)

pi = sym("Connector", "Raspberry_Pi_2_3", "J1", "Raspberry Pi Zero 2 W", PI_AT)
shim = sym("verbot", "OnOff_SHIM", "M1", "Pimoroni OnOff SHIM", (69.85, 63.5))
usb = sym("Connector", "USB_B_Micro", "J2", "5V USB power bank", (19.05, 63.5))

# USB bank -> SHIM. VBUS is pin 1 and shield/GND pin 5 on USB_B_Micro; confirm
# with pin_positions("Connector", "USB_B_Micro") and adjust if the stock symbol
# numbers them differently.
stub_label(usb["1"], "VBUS_IN", "R")
stub_label(usb["5"], "GND", "R")

# This is a power-only connection to a USB power bank; the data/ID/shield
# pins are intentionally unused, and J2 is not touched by any later task.
nc(usb["2"])  # D-
nc(usb["3"])  # D+
nc(usb["4"])  # ID
nc(usb["SH"])  # Shield

# Pi power pins. Pin numbers are physical header positions.
PI_5V = ["2", "4"]
PI_3V3 = ["1", "17"]
PI_GND = ["6", "9", "14", "20", "25", "30", "34", "39"]

for number in PI_5V:
    stub_label(pi[number], "+5V", "L")
for number in PI_3V3:
    stub_label(pi[number], "+3V3", "L")
for number in PI_GND:
    stub_label(pi[number], "GND", "R")

# OnOff SHIM: USB in, 5V out to the Pi rail, three GPIO lines.
stub_label(shim["1"], "VBUS_IN", "L")   # USB_5V_IN
stub_label(shim["2"], "GND", "L")
stub_label(shim["3"], "+5V", "R")       # 5V_OUT
stub_label(shim["4"], "SHIM_BTN", "R")  # BTN  - BCM17, Pi pin 11
stub_label(shim["5"], "SHIM_LED", "R")  # LED  - BCM27, Pi pin 13
stub_label(shim["6"], "SHIM_POWEROFF", "R")  # POWEROFF - BCM4, Pi pin 7

stub_label(pi["11"], "SHIM_BTN", "L")
stub_label(pi["13"], "SHIM_LED", "L")
stub_label(pi["7"], "SHIM_POWEROFF", "L")

# Power flags. Without one per externally-driven net, ERC errors with
# power_pin_not_driven. GND does not need one: the stock USB_B_Micro symbol
# types its pin 5 as a power output, so GND is already driven and adding a
# PWR_FLAG there trips a pin_to_pin "two power outputs" conflict instead.
for index, (net, at) in enumerate(
    [("+5V", (44.45, 105.41)), ("+3V3", (69.85, 105.41))]
):
    flag = sym("power", "PWR_FLAG", f"#FLG0{index + 1}", "PWR_FLAG", at, hide_value=True)
    label(net, flag["1"])

text_note(
    "POWER: 5V USB bank -> OnOff SHIM -> Pi 5V rail and DRV8833 VCC.\\n"
    "Motor current therefore passes through the SHIM load switch (~2A).\\n"
    "Cap VERBOT_ACTION_SPEED near +/-60 and rely on C1 for transients.",
    (25.4, 120.65),
)

# --------------------------------------------------------------------------
# Emit
# --------------------------------------------------------------------------

lib_cache = "\n".join(_lib_symbol_any(lib, name) for lib, name in USED_SYMBOLS)

DOC = f"""(kicad_sch
	(version 20260306)
	(generator "verbot-generate-schematic")
	(generator_version "10.0")
	(uuid "{ROOT_UUID}")
	(paper "A3")
	(title_block
		(title "verbot-pi-ng wiring")
		(date "2026-08-15")
		(rev "1")
		(comment 1 "Wiring documentation - not a PCB design")
		(comment 2 "Pin map source of truth: src/verbot/config.py")
	)
	(lib_symbols
{lib_cache}
	)
{chr(10).join(BODY)}
	(sheet_instances
		(path "/" (page "1"))
	)
	(embedded_fonts no)
)
"""

if __name__ == "__main__":
    with open("../verbot.kicad_sch", "w") as handle:
        handle.write(DOC)
    print(f"wrote hardware/verbot.kicad_sch ({len(BODY)} objects)")
```

- [ ] **Step 2: Generate and run ERC**

Run:
```bash
cd hardware/tools && python3 generate_schematic.py && cd ../.. && \
kicad-cli sch erc --severity-all --exit-code-violations hardware/verbot.kicad_sch; \
cat hardware/verbot-erc.rpt
```
Expected: `0 Errors 0 Warnings`, exit 0.

Common failures and their fixes:
- `endpoint_off_grid` — a coordinate is not a multiple of 1.27. `assert_grid` should have caught it; check any literal you typed.
- `power_pin_not_driven` — a `PWR_FLAG` label does not exactly match the net name it should drive.
- `pin_not_connected` — a Pi header pin has neither a stub nor a `no_connect`. Unused GPIO pins get `no_connect` in Task 8, so expect these until then; if they appear now, confirm they are only on pins Tasks 4–7 will claim, and proceed.

- [ ] **Step 3: Commit**

```bash
git add hardware/
git commit -m "feat(hardware): sheet generator and power tree"
```

---

### Task 4: Motor section

**Files:**
- Modify: `hardware/tools/generate_schematic.py` (insert before the `# Emit` banner)

**Interfaces:**
- Consumes: `sym`, `stub_label`, `wire`, `label`, `nc`, `text_note`, `pi` from Task 3.
- Produces: nets `MOTOR_IN1`, `MOTOR_IN2`, `MOTOR_nSLEEP`, `MOTOR_nFAULT`, `MOTOR_A`, `MOTOR_B`.

- [ ] **Step 1: Insert the motor section**

```python
# --------------------------------------------------------------------------
# Motor: DRV8833 channel A
# --------------------------------------------------------------------------

drv = sym("verbot", "DRV8833_Carrier", "M2", "DRV8833 carrier", (330.2, 63.5))
motor = sym("Motor", "Motor_DC", "M3", "Verbot 3V motor", (403.86, 76.2))
c1 = sym("Device", "C_Polarized", "C1", "470uF", (292.1, 76.2))

# Pi -> DRV8833. BCM numbers from src/verbot/config.py.
MOTOR_NETS = [
    ("32", "5", "MOTOR_IN1"),      # BCM12 PWM0  -> IN1
    ("33", "6", "MOTOR_IN2"),      # BCM13 PWM1  -> IN2
    ("31", "3", "MOTOR_nSLEEP"),   # BCM6        -> EEP
    ("36", "4", "MOTOR_nFAULT"),   # BCM16       <- ULT
]
for pi_pin, drv_pin, net in MOTOR_NETS:
    stub_label(pi[pi_pin], net, "R")
    stub_label(drv[drv_pin], net, "L")

stub_label(drv["1"], "+5V", "L")   # VCC
stub_label(drv["2"], "GND", "L")   # GND

# Bulk capacitance across the motor rail, at the carrier.
label("+5V", c1["1"])
label("GND", c1["2"])

# Channel A out to the motor.
stub_label(drv["7"], "MOTOR_A", "R")   # OUT1
stub_label(drv["8"], "MOTOR_B", "R")   # OUT2
stub_label(motor["1"], "MOTOR_A", "L")
stub_label(motor["2"], "MOTOR_B", "L")

# Channel B is unused.
for drv_pin in ("9", "10", "11", "12"):   # IN3, IN4, OUT3, OUT4
    nc(drv[drv_pin])

text_note(
    "MOTOR: only channel A is used.\\n"
    "EEP may be tied to VCC by the carrier's J1 solder jumper - check with a\\n"
    "meter. If bridged, set VERBOT_MOTOR_SLEEP_PIN=null and BCM6 stays free.\\n"
    "If the motor runs backwards, swap OUT1/OUT2 rather than the code's sign\\n"
    "convention: interrogation must be the positive direction.\\n"
    "VCC is the motor rail, NOT a logic rail - the 3V motor sees whatever it\\n"
    "is fed. Never feed it from the Pi's 3V3 pin.",
    (292.1, 116.84),
)
```

- [ ] **Step 2: Regenerate and run ERC**

Run:
```bash
cd hardware/tools && python3 generate_schematic.py && cd ../.. && \
kicad-cli sch erc --severity-all --exit-code-violations hardware/verbot.kicad_sch; \
cat hardware/verbot-erc.rpt
```
Expected: no new violations beyond unclaimed Pi GPIO pins.

If `Motor_DC` pin numbers are not `"1"` and `"2"`, run
`python3 -c "import sys; sys.path.insert(0,'hardware/tools'); from kicadgen import pin_positions; print(pin_positions('Motor','Motor_DC'))"`
and use the numbers it reports. Same technique for `C_Polarized`.

- [ ] **Step 3: Commit**

```bash
git add hardware/
git commit -m "feat(hardware): DRV8833 motor section"
```

---

### Task 5: Interrogation switch bank

**Files:**
- Modify: `hardware/tools/generate_schematic.py` (insert before the `# Emit` banner)

**Interfaces:**
- Consumes: `sym`, `stub_label`, `text_note`, `pi`.
- Produces: nets `SW_STOP`, `SW_ROTATE_RIGHT`, `SW_ROTATE_LEFT`, `SW_FORWARDS`, `SW_REVERSE`, `SW_PUT_DOWN`, `SW_PICK_UP`, `SW_TALK`.

- [ ] **Step 1: Insert the switch bank section**

```python
# --------------------------------------------------------------------------
# Interrogation switch bank - 9-core ribbon from the gearbox
# --------------------------------------------------------------------------

gearbox = sym("verbot", "Verbot_Gearbox", "M4", "Verbot gearbox harness", (330.2, 190.5))

# (gearbox pin, ribbon colour, Pi physical pin, net, BCM, interrogation order)
# Pin map is DEFAULT_SWITCH_PINS in src/verbot/config.py.
SWITCHES = [
    ("2", "PURPLE", "15", "SW_STOP", 22, 1),
    ("3", "RED", "37", "SW_ROTATE_RIGHT", 26, 2),
    ("4", "YELLOW", "19", "SW_ROTATE_LEFT", 10, 3),
    ("5", "GREY", "21", "SW_FORWARDS", 9, 4),
    ("6", "BLUE", "22", "SW_REVERSE", 25, 5),
    ("7", "BROWN", "23", "SW_PUT_DOWN", 11, 6),
    ("8", "ORANGE", "24", "SW_PICK_UP", 8, 7),
    ("9", "GREEN", "26", "SW_TALK", 7, 8),
]

for gearbox_pin, _colour, pi_pin, net, _bcm, _order in SWITCHES:
    stub_label(gearbox[gearbox_pin], net, "L")
    stub_label(pi[pi_pin], net, "R")

stub_label(gearbox["1"], "GND", "L")   # WHITE - common return
stub_label(gearbox["10"], "MOTOR_A", "R")
stub_label(gearbox["11"], "MOTOR_B", "R")

text_note(
    "INTERROGATION SWITCHES - all inputs, internal pull-ups, ACTIVE LOW.\\n"
    "White is the common ground return for all eight.\\n"
    "\\n"
    "  colour   order  action         BCM  Pi pin\\n"
    "  purple     1    stop            22    15\\n"
    "  red        2    rotate right    26    37\\n"
    "  yellow     3    rotate left     10    19\\n"
    "  grey       4    forwards         9    21\\n"
    "  blue       5    reverse         25    22\\n"
    "  brown      6    put down        11    23\\n"
    "  orange     7    pick up          8    24\\n"
    "  green      8    talk             7    26\\n"
    "\\n"
    "ARM LIMIT SWITCHES are in series inside the gearbox on BROWN and ORANGE.\\n"
    "When an arm reaches its travel limit that circuit OPENS - the controller\\n"
    "sees the switch release mid-action and stops. Without it the mechanism\\n"
    "strains against its stop.",
    (241.3, 215.9),
)
```

- [ ] **Step 2: Regenerate and run ERC**

Run:
```bash
cd hardware/tools && python3 generate_schematic.py && cd ../.. && \
kicad-cli sch erc --severity-all --exit-code-violations hardware/verbot.kicad_sch; \
cat hardware/verbot-erc.rpt
```
Expected: no new violations.

- [ ] **Step 3: Verify the pin map against the code**

Run:
```bash
python3 - <<'EOF'
import re
src = open("src/verbot/config.py").read()
block = re.search(r"DEFAULT_SWITCH_PINS.*?\{(.*?)\}", src, re.S).group(1)
code = dict(re.findall(r"Action\.(\w+):\s*(\d+)", block))
sch = {"STOP": "22", "ROTATE_RIGHT": "26", "ROTATE_LEFT": "10", "FORWARDS": "9",
       "REVERSE": "25", "PUT_DOWN": "11", "PICK_UP": "8", "TALK": "7"}
assert code == sch, f"MISMATCH\ncode={code}\nsch ={sch}"
print("switch pin map matches src/verbot/config.py")
EOF
```
Expected: `switch pin map matches src/verbot/config.py`

- [ ] **Step 4: Commit**

```bash
git add hardware/
git commit -m "feat(hardware): interrogation switch bank and limit switches"
```

---

### Task 6: Audio section

**Files:**
- Modify: `hardware/tools/generate_schematic.py` (insert before the `# Emit` banner)

**Interfaces:**
- Consumes: `sym`, `stub_label`, `nc`, `text_note`, `pi`.
- Produces: nets `I2S_BCLK`, `I2S_LRCLK`, `I2S_DIN`, `SPK_P`, `SPK_N`.

- [ ] **Step 1: Insert the audio section**

```python
# --------------------------------------------------------------------------
# Audio: MAX98357A I2S DAC / amplifier
# --------------------------------------------------------------------------

dac = sym("verbot", "MAX98357A_Breakout", "M5", "MAX98357A I2S DAC", (144.78, 215.9))
spk = sym("Device", "Speaker", "LS1", "4-8 ohm passive", (63.5, 228.6))

stub_label(dac["1"], "+5V", "L")   # VIN
stub_label(dac["2"], "GND", "L")   # GND

# Pi I2S -> DAC.
I2S_NETS = [
    ("12", "6", "I2S_BCLK"),    # BCM18 -> BCLK
    ("35", "7", "I2S_LRCLK"),   # BCM19 -> LRC
    ("40", "5", "I2S_DIN"),     # BCM21 -> DIN
]
for pi_pin, dac_pin, net in I2S_NETS:
    stub_label(pi[pi_pin], net, "L")
    stub_label(dac[dac_pin], net, "R")

# SD and GAIN ride the breakout's own pull-ups.
nc(dac["3"])   # SD
nc(dac["4"])   # GAIN

stub_label(dac["8"], "SPK_P", "R")
stub_label(dac["9"], "SPK_N", "R")
stub_label(spk["1"], "SPK_P", "L")
stub_label(spk["2"], "SPK_N", "L")

text_note(
    "AUDIO: MAX98357A on BCM18 (BCLK), 19 (LRCLK), 21 (DIN).\\n"
    "SD_MODE is left floating on the breakout's own pull-up. That is what the\\n"
    "no-sdmode flag in config/config.txt.example selects - without it the\\n"
    "overlay claims BCM4, which the OnOff SHIM needs for shutdown.\\n"
    "GAIN floating = 9dB default. Speaker must be PASSIVE, 4-8 ohm.",
    (63.5, 254.0),
)
```

- [ ] **Step 2: Regenerate and run ERC**

Run:
```bash
cd hardware/tools && python3 generate_schematic.py && cd ../.. && \
kicad-cli sch erc --severity-all --exit-code-violations hardware/verbot.kicad_sch; \
cat hardware/verbot-erc.rpt
```
Expected: no new violations.

- [ ] **Step 3: Commit**

```bash
git add hardware/
git commit -m "feat(hardware): MAX98357A audio section"
```

---

### Task 7: Front panel — MCP23017, keypad, status LED

**Files:**
- Modify: `hardware/tools/generate_schematic.py` (insert before the `# Emit` banner)

**Interfaces:**
- Consumes: `sym`, `stub_label`, `wire`, `label`, `nc`, `text_note`, `pi`.
- Produces: nets `I2C_SDA`, `I2C_SCL`, `BTN_<ACTION>` ×8, `LED_A`.

- [ ] **Step 1: Insert the front-panel section**

```python
# --------------------------------------------------------------------------
# Front panel: MCP23017 expander, 8 keypad buttons, status LED
# --------------------------------------------------------------------------

mcp = sym("verbot", "MCP23017_Breakout", "M6", "MCP23017 @ 0x20", (76.2, 165.1))

stub_label(mcp["1"], "+3V3", "L")   # VDD
stub_label(mcp["2"], "GND", "L")    # VSS
stub_label(mcp["3"], "I2C_SDA", "L")
stub_label(mcp["4"], "I2C_SCL", "L")
stub_label(mcp["5"], "+3V3", "L")   # RESET held high

# A0/A1/A2 to GND -> address 0x20, matching Settings.mcp23017_address.
for mcp_pin in ("6", "7", "8"):
    stub_label(mcp[mcp_pin], "GND", "L")

# Interrupts unused: Mcp23017Keypad polls at 50 Hz.
nc(mcp["9"])    # INTA
nc(mcp["10"])   # INTB

stub_label(pi["3"], "I2C_SDA", "L")   # BCM2
stub_label(pi["5"], "I2C_SCL", "L")   # BCM3

# GPA0-7 -> the eight original red buttons, common side to GND.
# Order is BUTTON_ORDER in src/verbot/hardware/mcp23017.py.
BUTTON_ORDER = [
    "STOP",
    "FORWARDS",
    "REVERSE",
    "ROTATE_LEFT",
    "ROTATE_RIGHT",
    "PICK_UP",
    "PUT_DOWN",
    "TALK",
]
for index, action in enumerate(BUTTON_ORDER):
    mcp_pin = str(11 + index)          # GPA0 is pin 11 in the block symbol
    net = f"BTN_{action}"
    stub_label(mcp[mcp_pin], net, "R")
    button = sym(
        "Switch", "SW_Push", f"SW{index + 1}", action.lower(),
        (12.7, round(139.7 + index * 10.16, 2)),
    )
    stub_label(button["1"], net, "L")
    stub_label(button["2"], "GND", "R")

# GPB0 -> series resistor -> status LED -> GND.
led_r = sym("Device", "R", "R1", "330", (152.4, 165.1))
led = sym("Device", "LED", "D1", "red status", (152.4, 180.34))
stub_label(mcp["19"], "LED_DRIVE", "R")   # GPB0
label("LED_DRIVE", led_r["1"])
label("LED_A", led_r["2"])
# pin_positions("Device", "LED") -> pin "1" is K (cathode), pin "2" is A
# (anode). Anode gets the driven net; cathode goes to GND.
label("LED_A", led["2"])
label("GND", led["1"])

# GPB1-7 are configured as inputs by the driver and left floating.
for index in range(1, 8):
    nc(mcp[str(19 + index)])

text_note(
    "FRONT PANEL - VERIFY BEFORE WIRING.\\n"
    "This assumes the eight buttons are INDEPENDENT switches to a common rail.\\n"
    "That has NOT been confirmed on the real panel. The original PCB also\\n"
    "carried the power switching, so bypass it and solder to the switch\\n"
    "contacts directly. Check with a meter first.\\n"
    "\\n"
    "GPA0-7 are inputs with MCP23017 pull-ups enabled: ACTIVE LOW.\\n"
    "Button order above is BUTTON_ORDER in hardware/mcp23017.py and is a\\n"
    "GUESS - reorder it at bring-up if a button triggers the wrong action.\\n"
    "R1 330R gives ~5mA from 3V3 through a red LED; MCP23017 sources 25mA.\\n"
    "GPB1-7 float (driver sets them as inputs) - harmless.",
    (12.7, 254.0),
)
```

- [ ] **Step 2: Regenerate and run ERC**

Run:
```bash
cd hardware/tools && python3 generate_schematic.py && cd ../.. && \
kicad-cli sch erc --severity-all --exit-code-violations hardware/verbot.kicad_sch; \
cat hardware/verbot-erc.rpt
```
Expected: no new violations.

- [ ] **Step 3: Verify button order against the code**

Run:
```bash
python3 - <<'EOF'
import re
src = open("src/verbot/hardware/mcp23017.py").read()
block = re.search(r"BUTTON_ORDER.*?\((.*?)\)", src, re.S).group(1)
code = re.findall(r"Action\.(\w+)", block)
sch = ["STOP", "FORWARDS", "REVERSE", "ROTATE_LEFT",
       "ROTATE_RIGHT", "PICK_UP", "PUT_DOWN", "TALK"]
assert code == sch, f"MISMATCH\ncode={code}\nsch ={sch}"
print("button order matches src/verbot/hardware/mcp23017.py")
EOF
```
Expected: `button order matches src/verbot/hardware/mcp23017.py`

- [ ] **Step 4: Commit**

```bash
git add hardware/
git commit -m "feat(hardware): MCP23017 front panel, keypad and status LED"
```

---

### Task 8: Unused Pi pins, final ERC clean

**Files:**
- Modify: `hardware/tools/generate_schematic.py` (insert before the `# Emit` banner)

**Interfaces:**
- Consumes: `nc`, `pi`, `text_note`.
- Produces: an ERC-clean sheet.

- [ ] **Step 1: Insert the unused-pin section**

```python
# --------------------------------------------------------------------------
# Unused header pins
# --------------------------------------------------------------------------

# Every Pi pin claimed above, so the rest can be no-connected without guessing.
CLAIMED = set(
    PI_5V + PI_3V3 + PI_GND
    + ["11", "13", "7"]                                  # OnOff SHIM
    + [pi_pin for pi_pin, _, _ in MOTOR_NETS]            # DRV8833
    + [pi_pin for _, _, pi_pin, _, _, _ in SWITCHES]     # switch bank
    + [pi_pin for pi_pin, _, _ in I2S_NETS]              # I2S DAC
    + ["3", "5"]                                         # I2C
)

for number in pi:
    if number not in CLAIMED:
        nc(pi[number])

text_note(
    "FREE GPIO after this build: BCM 5, 14, 15, 20, 23, 24.\\n"
    "Unused header pins carry no-connect flags so ERC stays meaningful.",
    (215.9, 254.0),
)
```

- [ ] **Step 2: Regenerate and run ERC — this is the gate**

Run:
```bash
cd hardware/tools && python3 generate_schematic.py && cd ../.. && \
kicad-cli sch erc --severity-all --exit-code-violations hardware/verbot.kicad_sch; \
echo "exit=$?"; cat hardware/verbot-erc.rpt
```
Expected: `** ERC messages: 0  Errors 0  Warnings 0` and `exit=0`.

Do not proceed until this is exactly zero. If violations remain:
- `endpoint_off_grid` — an off-grid literal slipped past `assert_grid`; grep the file for coordinates and check each against 1.27.
- `no_connect_dangling` — a `nc()` is not exactly on a pin. Print the pin dict for that symbol and compare.
- `pin_not_connected` — a module pin has neither a stub nor a no-connect.
- `power_pin_not_driven` — a net that feeds a power-input pin has no `PWR_FLAG`.
- `label_dangling` — a net label appears only once. Every net name must appear at both ends.

- [ ] **Step 3: Commit**

```bash
git add hardware/
git commit -m "feat(hardware): no-connect unused header pins, ERC clean"
```

---

### Task 9: Export, document, publish

**Files:**
- Create: `hardware/verbot-schematic.pdf`
- Create: `hardware/verbot-schematic.svg`
- Modify: `docs/hardware.md`
- Modify: `README.md`

- [ ] **Step 1: Export PDF and SVG**

Run:
```bash
kicad-cli sch export pdf -o hardware/verbot-schematic.pdf hardware/verbot.kicad_sch && \
kicad-cli sch export svg --exclude-drawing-sheet -o /tmp/verbot-svg hardware/verbot.kicad_sch && \
cp /tmp/verbot-svg/verbot.svg hardware/verbot-schematic.svg && \
ls -la hardware/verbot-schematic.*
```
Expected: both files exist and are non-empty.

If `--exclude-drawing-sheet` is rejected, drop the flag — it only omits the border.

- [ ] **Step 2: Read the PDF and check it visually**

Open `hardware/verbot-schematic.pdf` and confirm:
- No block overlaps another block or a text note
- Every net label is legible and not colliding with a wire
- The title block reads "verbot-pi-ng wiring"
- All six notes are on the sheet and inside the border

If blocks overlap, adjust the `at=` coordinates in `generate_schematic.py` (keeping every value a multiple of 1.27), regenerate, re-run ERC, and re-export.

- [ ] **Step 3: Link the schematic from `docs/hardware.md`**

Insert immediately after the attribution blockquote at the top:

```markdown
> 📐 **Schematic:** [`hardware/verbot-schematic.pdf`](../hardware/verbot-schematic.pdf)
> — the full wiring on one sheet. Source: [`hardware/verbot.kicad_sch`](../hardware/verbot.kicad_sch)
> (KiCad 10). The GPIO table below and `src/verbot/config.py` remain the pin-map
> source of truth; the schematic reproduces them.
```

- [ ] **Step 4: Link it from `README.md`**

In the `## Hardware` section, change:

```markdown
Wiring, pin assignments and the reverse-engineered mechanical details are in
[`docs/hardware.md`](docs/hardware.md).
```

to:

```markdown
Wiring, pin assignments and the reverse-engineered mechanical details are in
[`docs/hardware.md`](docs/hardware.md), and the full schematic is at
[`hardware/verbot-schematic.pdf`](hardware/verbot-schematic.pdf).
```

- [ ] **Step 5: Final verification**

Run:
```bash
cd hardware/tools && python3 selftest.py && cd ../.. && \
kicad-cli sch erc --severity-all --exit-code-violations hardware/verbot.kicad_sch && \
uv run pytest -q && uv run ruff check
```
Expected: self-test passes, ERC exits 0, the existing Python suite still passes, ruff clean.

The Python suite must be untouched by this work — if it fails, something outside `hardware/` was modified.

- [ ] **Step 6: Commit and push**

```bash
git add hardware/ docs/hardware.md README.md
git commit -m "feat(hardware): KiCad wiring schematic with PDF/SVG exports"
git push origin main
```

---

## Notes for the implementer

**On the generator.** Tasks 3–8 build one Python file incrementally, each appending a section before the `# Emit` banner. That ordering matters: `BODY` and `USED_SYMBOLS` are populated at import time, and the `DOC` f-string reads them.

**On coordinates.** Every `at=` in this plan is a multiple of 1.27 and was chosen to keep blocks apart on a 420×297mm sheet. They are starting positions, not sacred — if the PDF looks cramped, move them. Just keep them on grid.

**On what this is not.** No footprints, no netlist for fabrication, no PCB. If a task tempts you toward assigning footprints, it is out of scope.

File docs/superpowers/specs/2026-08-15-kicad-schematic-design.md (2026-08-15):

# KiCad wiring schematic — design

**Date:** 2026-08-15
**Status:** approved, ready for implementation

## Goal

Produce a KiCad schematic documenting how every part of the robot wires to the
Raspberry Pi Zero 2 W, readable enough to build and debug from at the bench.

This is **wiring documentation, not a PCB design**. No footprints, no netlist
for fabrication, no board layout. Modules are drawn as block symbols with the
pin names silkscreened on the real boards, because the modules are bought
boards being hand-wired — not chips being designed in.

`src/verbot/config.py` and `docs/hardware.md` are the source of truth for pin
assignments. The schematic reproduces them; it does not invent any.

## Deliverables

```
hardware/
  verbot.kicad_pro          project file
  verbot.kicad_sch          single A3 sheet
  verbot.kicad_sym          project symbol library (module blocks)
  sym-lib-table             registers verbot.kicad_sym as "verbot"
  verbot-schematic.pdf      exported, committed
  verbot-schematic.svg      exported, committed
```

`hardware/` is a new top-level directory. `docs/` is prose; this is neither
prose nor Python. The PDF and SVG are committed so the wiring is readable from
GitHub without KiCad installed — the realistic case is standing at the bench
with a phone.

`docs/hardware.md` gains a link to the PDF near the top. Its GPIO table stays
where it is; that table is what gets grepped.

Target: KiCad 10.0.5, symbol library format version 20251024.

## Symbol library

Five block symbols in `verbot.kicad_sym`. Each is a labelled rectangle whose
pins carry the names printed on the actual board, so the schematic reads the
same as the part in your hand.

| Symbol | Pins |
|---|---|
| `DRV8833_Carrier` | `VCC` `GND` `IN1` `IN2` `IN3` `IN4` `OUT1` `OUT2` `OUT3` `OUT4` `EEP` `ULT` |
| `MAX98357A_Breakout` | `VIN` `GND` `SD` `GAIN` `DIN` `BCLK` `LRC` `+` `-` |
| `MCP23017_Breakout` | `VDD` `VSS` `SDA` `SCL` `RESET` `A0` `A1` `A2` `INTA` `INTB` `GPA0`–`GPA7` `GPB0`–`GPB7` |
| `OnOff_SHIM` | `USB_5V_IN` `5V_OUT` `GND` `BTN` `LED` `POWEROFF` |
| `Verbot_Gearbox` | `WHITE_GND` `PURPLE` `RED` `YELLOW` `GREY` `BLUE` `BROWN` `ORANGE` `GREEN` `MOTOR_A` `MOTOR_B` |

`Verbot_Gearbox` names its pins by ribbon-cable wire colour. Those colours are
what you are physically holding when you strip that 9-core cable, and mapping
colour to BCM number is the single step where an error is most expensive.

Stock symbols for everything else:

- `Connector:Raspberry_Pi_2_3` — the 40-pin header. Electrically identical on a
  Zero 2 W; the symbol name refers to the header pinout, not the board model.
- `Device:Speaker`, `Motor:Motor_DC`, `Device:LED`, `Device:R`,
  `Device:C_Polarized`, `Switch:SW_Push`
- `Connector:USB_B_Micro` for the power bank's cable into the OnOff SHIM,
  labelled as the 5V bank rather than drawn as a battery

## Sheet layout

Single A3 sheet. Pi header centred, six blocks around it. Signals travel by net
label off short pin stubs rather than long routed wires — the readable
convention for a 40-pin part, and it keeps the S-expressions tractable.

```
┌─A3──────────────────────────────────────┐
│ [USB bank]   ┌───────┐      [DRV8833]   │
│ [OnOff SHIM] │  Pi   │      [MOTOR]     │
│              │ Zero  │                  │
│ [MCP23017]   │ 2 W   │   [GEARBOX SW]   │
│ [KEYPAD ×8]  └───────┘   [LIMIT SW ×2]  │
│ [STATUS LED]        [MAX98357A][SPKR]   │
└─────────────────────────────────────────┘
```

### Power

`USB bank → OnOff SHIM → +5V`, feeding Pi pins 2/4 and DRV8833 `VCC`.
`C1` 470µF polarised across the motor rail at the carrier. Pi pin 1 (`+3V3`)
feeds MCP23017 `VDD`. All grounds common; Pi pins 6/9/14/20/25/30/34/39 to
`GND`.

**Known tradeoff, accepted:** routing DRV8833 `VCC` downstream of the OnOff
SHIM puts motor current through the SHIM's load switch, rated around 2A. A 3V
motor stalled on a 5V rail can transiently exceed that, and the failure mode is
the SHIM cutting power — the Pi drops mid-action and it looks like a software
hang. Mitigated by the 470µF bulk cap, by capping `VERBOT_ACTION_SPEED` near
±60 (already a bring-up measurement), and by the existing stall watchdog. The
schematic carries this as a note so the current path is visible to anyone
reading it. Alternatives considered and rejected for now: tapping 5V upstream
of the SHIM (motor rail stays live at soft-off), or upstream plus a load switch
gated on `MOTOR_nSLEEP` (extra part).

### Motor

| Net | BCM | Pi pin | DRV8833 |
|---|---|---|---|
| `MOTOR_IN1` | 12 | 32 | `IN1` |
| `MOTOR_IN2` | 13 | 33 | `IN2` |
| `MOTOR_nSLEEP` | 6 | 31 | `EEP` |
| `MOTOR_nFAULT` | 16 | 36 | `ULT` |

`OUT1`/`OUT2` to `Motor:Motor_DC`. `IN3`/`IN4`/`OUT3`/`OUT4` get explicit
no-connect flags — channel B is unused.

Notes on the sheet: `EEP` may be tied to `VCC` by the carrier's `J1` solder
jumper, in which case set `VERBOT_MOTOR_SLEEP_PIN` to `null`; and swap
`OUT1`/`OUT2` rather than the code's sign convention if the motor runs
backwards, because interrogation must be the positive direction.

### Interrogation switches

`Verbot_Gearbox` block, one net per ribbon colour. White is the common ground
return. Inputs use the Pi's internal pull-ups and are active low.

| Colour | Order | Net | BCM | Pi pin |
|---|---|---|---|---|
| Purple | 1 | `SW_STOP` | 22 | 15 |
| Red | 2 | `SW_ROTATE_RIGHT` | 26 | 37 |
| Yellow | 3 | `SW_ROTATE_LEFT` | 10 | 19 |
| Grey | 4 | `SW_FORWARDS` | 9 | 21 |
| Blue | 5 | `SW_REVERSE` | 25 | 22 |
| Brown | 6 | `SW_PUT_DOWN` | 11 | 23 |
| Orange | 7 | `SW_PICK_UP` | 8 | 24 |
| Green | 8 | `SW_TALK` | 7 | 26 |

Matches `DEFAULT_SWITCH_PINS` in `src/verbot/config.py`.

The arm limit switches are drawn **inline** on Brown and Orange. `docs/hardware.md`
describes them in prose but no diagram has shown them, and they are why those
two lines can open mid-action — the signal the controller uses to stop.

### Audio

`+5V` to `VIN`. `I2S_BCLK` BCM18/pin12, `I2S_LRCLK` BCM19/pin35, `I2S_DIN`
BCM21/pin40. Speaker terminals to `Device:Speaker` (4–8Ω passive).

`SD` and `GAIN` no-connect. Sheet note ties `SD` to the `no-sdmode` flag in
`config/config.txt.example`: leaving it floating on the breakout's own pull-up
is what keeps BCM4 free for the OnOff SHIM.

### Front panel

`I2C_SDA` BCM2/pin3, `I2C_SCL` BCM3/pin5. `A0`/`A1`/`A2` to `GND` giving
address 0x20, matching `mcp23017_address`. `RESET` to `+3V3`. `INTA`/`INTB`
no-connect, with a note that `Mcp23017Keypad` polls at 50 Hz rather than using
the interrupt line.

`GPA0`–`GPA7` to eight `SW_Push` switches, common side to `GND`, in the
`BUTTON_ORDER` from `src/verbot/hardware/mcp23017.py`: Stop, Forwards, Reverse,
Rotate left, Rotate right, Pick up, Put down, Talk.

`GPB0` to `R1` 330Ω to the status LED to `GND`. 330Ω gives roughly 5mA from the
3.3V rail through a red LED; the MCP23017 sources up to 25mA per pin.

`GPB1`–`GPB7` no-connect. The driver configures them as inputs, so they float;
harmless, and noted on the sheet.

**Boxed note on the keypad**, reproducing the warning in `docs/hardware.md`:
this wiring assumes the eight buttons are independent switches to a common
rail. That has not been verified. The original PCB also carried the power
switching, so the intended approach is to bypass it and solder to the switch
contacts directly. Verify with a meter before wiring. `BUTTON_ORDER` is a guess
and may need reordering at bring-up.

## Verification

`kicad-cli sch erc` must report zero errors and zero warnings before commit.
This is a real check, not a formality — it catches unconnected pins, net-label
typos that silently split one net into two, and power-input pins with no
driving source. Those are the three mistakes that would cost bench time.

Reaching zero warnings requires:

- No-connect flags on `IN3` `IN4` `OUT3` `OUT4` `SD` `GAIN` `INTA` `INTB`
  `GPB1`–`GPB7`
- `PWR_FLAG` on `+5V`, `+3V3` and `GND` so ERC knows they are externally driven

Then `kicad-cli sch export pdf` and `kicad-cli sch export svg`.

No automated tests. This is a drawing; ERC is the verification. Actual ERC
output gets reported, not a claim that it passed.

## Out of scope

- PCB layout, footprints, fabrication outputs
- Drawing the internals of bought modules
- A matrix-wired keypad variant — would need a `decode_buttons()` rewrite
- Changes to any Python source

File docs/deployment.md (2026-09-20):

# Deploying to the Pi Zero 2 W

## 1. Base image

Flash **64-bit Raspberry Pi OS (Trixie)**. The 64-bit build matters: it gets
prebuilt aarch64 wheels for `pydantic-core`, avoiding a from-source Rust build
that a Zero would struggle to finish.

## 2. Headless first boot

Raspberry Pi OS ships in two variants that provision from **different files**.
Check `bootfs` before writing anything — the wrong file is silently ignored,
and you get the interactive user-creation wizard on a robot with no keyboard:

| On `bootfs` | Variant | Provision with |
|---|---|---|
| `user-data`, `meta-data`, `network-config` | cloud-init | `user-data` + `network-config` |
| neither, and `cmdline.txt` contains `init=/usr/lib/raspberrypi-sys-mods/firstboot` | standard | `custom.toml` |

We use the **cloud-init** variant. Replace the two stock templates, which ship
entirely commented out and therefore do nothing.

`user-data`:

```yaml
#cloud-config
hostname: verbot
manage_etc_hosts: true

bootcmd:
  - [ systemctl, disable, userconfig.service ]
  - [ systemctl, enable, getty@tty1.service ]

users:
  - name: bkrein
    shell: /bin/bash
    groups: [adm, sudo, users, dialout, audio, video, plugdev, netdev, gpio, i2c]
    sudo: "ALL=(ALL) NOPASSWD:ALL"
    lock_passwd: false
    passwd: "$6$..."          # openssl passwd -6 'yourpassword'
    ssh_authorized_keys:
      - "ssh-ed25519 AAAA... you@workstation"

ssh_pwauth: false
timezone: America/New_York

runcmd:
  - [ systemctl, enable, --now, ssh ]
```

`network-config`:

```yaml
network:
  version: 2
  wifis:
    wlan0:
      dhcp4: true
      optional: true
      access-points:
        "YourNetwork":
          password: "your-wifi-passphrase"
      regulatory-domain: US
```

Then in `meta-data`, set **`instance-id`** — with a hyphen — to a new value:

```yaml
dsmode: local
instance-id: verbot-2026-08-16-02
```

This is the single most important line, and the stock template gets it wrong.
It ships `instance_id` with an **underscore**, which is not a cloud-init key at
all. cloud-init reads `instance-id` (see `iid_key` in `DataSourceNoCloud.py`),
so with the underscore spelling the id silently stays at its NoCloud default of
`nocloud` forever. Every `once-per-instance` module — `users_groups`,
`set_passwords`, `ssh` — then runs on the very first boot and is skipped on
every boot after, no matter how many times you edit `user-data`.

The failure is deeply misleading, because `update_hostname` runs
`once-per-always`. Your new hostname appears, which looks like the config was
applied, while no user was ever created. If `/etc/hostname` is right but
`/etc/passwd` has only pi-gen's `pi` placeholder, this is why.

The `bootcmd` block retires the first-boot wizard. `userconfig.service` is
enabled and prompts for a username on **every** boot until something calls
`cancel-rename`, which nothing does on a declaratively provisioned image.
`bootcmd` runs in the init stage, well before `multi-user.target`, so it cannot
race the wizard. Re-enabling `getty@tty1` is not optional: the image ships it
disabled because the wizard owns the console, so disabling the wizard alone
leaves no console login at all.

Use canonical timezone names. Debian 13 moved legacy names like `US/Eastern`
into the separate `tzdata-legacy` package, which a Lite image does not carry —
`cc_timezone` raises `IOError` and the module fails. `America/New_York` works.
Note that `timedatectl` on an Arch workstation happily reports the legacy name,
so copying it across is an easy mistake.

**List `gpio` and `i2c` here, not only in step 6.** `cc_users_groups` re-applies
this list verbatim every time `instance-id` changes, so any group added later
with `usermod` is silently removed on the next re-provision. That drops write
access to `/sys/class/pwm` (`root:gpio`, mode 770) and the service dies at
startup with `PermissionError: … '/sys/class/pwm/pwmchip0/export'`, which looks
nothing like a user-management problem.

Both groups exist on a stock Raspberry Pi OS image. Do not add speculative
groups — a name that does not exist makes `useradd` fail and takes the whole
user creation down with it, landing you back at the wizard.

`optional: true` keeps a missing access point from blocking boot. The robot is
built to run its panel buttons with no network (bring-up checklist step 7), so a
hung boot is the worse failure.

### If it comes up at the wizard anyway

Reseat the card and read `bootfs`. The state of the provisioning file says which
half of the pipeline broke:

- **`custom.toml` still present** — you are on the cloud-init variant and it was
  never read. The standard variant *deletes* the file after applying it.
- **`/etc/hostname` correct but no user in `/etc/passwd`** — `instance-id` was
  unchanged, so the per-instance modules were skipped. Confirm with
  `ls /var/lib/cloud/instances/`: a directory named `nocloud` rather than your
  id means the key never took effect.
- **A module failed** — `grep -E "WARNING|Traceback" /var/log/cloud-init.log` on
  `rootfs`. The log is `root:0640`, so it needs sudo to read.
- **The Pi has no network but is otherwise configured** — the Zero 2 W radio is
  2.4 GHz only. Confirm the SSID exists on 2.4 GHz with WPA2.

Timestamps in that log are unreliable. The Zero 2 W has no RTC, so `fake-hwclock`
restores the image build date and every entry looks months old. Judge ordering by
sequence, never by clock time.

The pre-Bookworm `ssh` and `wpa_supplicant.conf` files work on neither variant.
Trixie uses NetworkManager, and `wpa_supplicant.conf` in the boot partition is
ignored outright.

## Fast path: the install script

Steps 3–8 are automated. Once you can SSH in:

```bash
curl -LsSf https://raw.githubusercontent.com/benjamink/verbot-pi-ng/main/scripts/install.sh | bash
```

It is idempotent — re-run it after a push to update the checkout and
dependencies. It refuses to run on anything that is not a 64-bit Raspberry Pi,
backs up `config.txt` to `config.txt.verbot-backup` before appending, and marks
its additions with `# >>> verbot-pi-ng >>>` so a second run is a no-op.

The service is enabled, so it starts on boot and the panel buttons are live.
**Put the robot on a stand with its wheels off the ground before rebooting.**

The script enables the service but does not start it before the reboot: the PWM
overlay is not loaded until then, so starting early would fail on a missing
`pwmchip0` and trip `Restart=on-failure`.

The rest of this document explains what the script does, and is what to follow
if you would rather work through it by hand.

## 3. Firmware config

Append the contents of [`../config/config.txt.example`](../config/config.txt.example)
to `/boot/firmware/config.txt` and reboot. Then verify:

`dtparam=i2c_arm=on` brings up the bus but does **not** create the `/dev/i2c-*`
character devices that `smbus2` opens. Those need the `i2c-dev` module, which
nothing loads by default — `raspi-config`'s "enable I2C" does both halves, and
the dtparam is only the first:

```bash
sudo modprobe i2c-dev
echo i2c-dev | sudo tee -a /etc/modules   # survive a reboot
```

Then verify:

```bash
ls /sys/class/pwm/          # expect pwmchip0
cat /sys/class/pwm/pwmchip0/npwm   # expect 2 — pwm-2chan gives both channels
aplay -l                    # expect the MAX98357A card
ls /dev/i2c-*               # expect /dev/i2c-1
i2cdetect -y 1              # expect a device at 0x20
```

If `pwmchip0` is absent or numbered differently, set `VERBOT_PWM_CHIP`
accordingly — kernel PWM chip numbering has shifted between OS releases.

If `/sys/bus/i2c/devices/` lists `i2c-1` but `/dev/i2c-1` is missing, the bus is
enabled and only `i2c-dev` is absent. A missing MCP23017 is not the cause: the
bus node exists whether or not anything is wired to it, and shows up as an empty
`i2cdetect` grid rather than a missing device file.

**Append the block once.** If you have already appended it by hand, the install
script will detect the existing `dtoverlay=pwm-2chan` and skip rather than add a
second copy — duplicated `dtoverlay` lines load the overlays twice.

If `npwm` reads 1, the single-channel `pwm` overlay is still in place. The
DRV8833 needs `pwm-2chan`: it has no PHASE/ENABLE mode, so both IN1 and IN2
need a PWM channel.

## 4. System packages

```bash
sudo apt update
sudo apt install -y espeak-ng i2c-tools
sudo apt install -y build-essential python3-dev swig liblgpio-dev
espeak-ng "hello"      # confirm audio reaches the speaker
```

The second line is the build toolchain for `lgpio`. It publishes aarch64 wheels
only up to **cp312**, and this image runs CPython 3.13, so there is no wheel to
match and `uv` compiles the sdist here. `uv.lock` records only the sdist for the
same reason, so this is not something a lockfile refresh avoids. Without these
packages the sync fails at `error: command 'swig' failed`.

## 5. Install

```bash
curl -LsSf https://astral.sh/uv/install.sh | sh
git clone https://github.com/benjamink/verbot-pi-ng.git ~/verbot-pi-ng
cd ~/verbot-pi-ng
uv sync --extra pi --frozen
```

`--frozen` installs exactly the committed `uv.lock`.

## 6. Permissions

```bash
sudo usermod -aG gpio,i2c,audio "$USER"
```

Log out and back in. If writes to `/sys/class/pwm` still fail, check for a udev
rule granting the `gpio` group access; add `/etc/udev/rules.d/99-pwm.rules` if
your image lacks one.

## 7. First run

```bash
VERBOT_USE_REAL_HARDWARE=true uv run verbot
```

Without that variable the server runs on fakes and the robot will not move —
useful for testing the API on any machine, confusing if you forget it on the Pi.
Look for the absence of the `running on fake hardware` warning in the log.

## 8. Service

```bash
sudo cp config/verbot.service /etc/systemd/system/verbot@.service
sudo systemctl daemon-reload
sudo systemctl enable --now verbot@$USER
journalctl -u verbot@$USER -f
```

Put `VERBOT_USE_REAL_HARDWARE=true` in a `.env` file in the working directory,
or add `Environment=` lines to the unit.

## 9. Shutdown endpoint (optional)

Without the OnOff SHIM there is no power button, and pulling USB power without
a clean shutdown risks corrupting the SD card. This endpoint gives you a
shutdown over HTTP. It is off unless you enable it.

Put this in the working directory's `.env`:

```
VERBOT_SHUTDOWN_ENABLED=true
```

It is unauthenticated, same as the rest of the API — anything on the LAN that
can already drive the robot can power it off too. If that is not an
acceptable trade-off on your network, leave this unset; the web page's
**Shut down the Pi** button only asks for an in-browser confirmation, not a
credential, so it is a guard against a misclick rather than against a hostile
network.

If you set the variable, restarted the service (below), and still get a 404,
that is deliberate, not a bug — a 404 before the restart just means the
running process has not read the new `.env` yet.

The service runs unprivileged, so `poweroff` needs one narrow grant. Check the
real path first — it is `/usr/sbin` on Trixie and `/sbin` on older images:

```bash
command -v poweroff
```

```bash
sudo visudo -f /etc/sudoers.d/verbot-poweroff
```

Add one line, then save:

```
verbot ALL=(root) NOPASSWD: /usr/sbin/poweroff
```

Replace `verbot` with the user the service runs as, and the path with whatever
`command -v poweroff` reported. Scope it to that one binary — never
`NOPASSWD: ALL`. A wrong path fails closed, which at least is the safe
direction.

`visudo -f` validates before it writes the file and refuses to save something
broken, and it sets the `0440` mode itself — unlike `tee` followed by `chmod`
and a separate `visudo -c`, which installs the file before checking it.
Root has no password on Raspberry Pi OS and sudo refuses to run at all while
anything in `sudoers.d` is unparseable, so a mistake caught only after
installing means physical access or pulling the SD card to fix it. Keep a
second root shell open (`sudo -i` in another terminal) while you edit, as the
standard precaution, in case something elsewhere in `sudoers.d` is already
broken.

Restart the service so it picks up both the setting and the grant — the route
is registered once at startup, so editing `.env` alone does nothing until the
process restarts:

```bash
sudo systemctl restart verbot@$USER
```

Confirm the grant works without powering anything off:

```bash
sudo -n -l /usr/sbin/poweroff
```

That lists the command with no password prompt. If it prompts for one or
refuses, fix the grant before going further — the endpoint will fail the same
way.

Then, **this actually shuts the Pi down**:

```bash
curl -X POST localhost:8080/system/shutdown
```

```json
{"status": "shutting down"}
```

The 202 is not proof it worked — it is returned before the poweroff is even
attempted, so a wrong sudoers grant looks identical to success: same
response, machine stays up. Confirm the Pi actually went down. If it did not,
`journalctl -u verbot@$USER` will have the `poweroff exited …` line logged by
`system_power.py`, with sudo's own diagnostic attached.

Polkit is not an alternative here: a systemd service has no seat or login
session, so the usual "a local user may power off without sudo" path does not
apply.

**Worth knowing:** this endpoint is unauthenticated, same as the rest of the
API, which has none at all while advertising itself over mDNS — anything on
the network can already drive the robot, and now power it off too. Acceptable
on a home LAN; worth thinking about before exposing the robot more widely,
since there is nothing here to stop it beyond the web page's confirmation
prompt, which a direct `curl` skips entirely.

## Bring-up checklist

There is a control page at **`http://verbot.local:8080/`** covering every step
below except the panel buttons: action buttons, a large stop, live status, a
speak box, live speed sliders, and a log of each request and response. It calls
the same endpoints as the `curl` commands here, so either works. With
`VERBOT_SHUTDOWN_ENABLED=true` it also offers a shutdown control, which asks
for confirmation in the browser before sending the request.

Work through these in order, with the robot **on a stand with its wheels off
the ground** until step 5 passes. Keep the schematic open while you do —
[`hardware/verbot-schematic.pdf`](../hardware/verbot-schematic.pdf)
([SVG](../hardware/verbot-schematic.svg)).

| # | Check | Command / action | Expected |
|---|---|---|---|
| 1 | Server healthy | `curl -s localhost:8080/healthz` | `{"status":"ok"}` |
| 2 | Switches read | Turn the drum **by hand**, watch `journalctl -f` | each switch logs a close then an open |
| 3 | Interrogation → action | `curl -X POST localhost:8080/actions/talk` | motor runs, then reverses when the talk switch closes |
| 4 | Stop | `curl -X POST localhost:8080/stop` | motor stops at the stop position |
| 5 | Limit switch | `curl -X POST localhost:8080/actions/pick_up` | arms rise and **stop at the top by themselves** |
| 6 | Speech | `curl -X POST localhost:8080/say -H 'content-type: application/json' -d '{"text":"I am Verbot"}'` | audible |
| 7 | Panel buttons | `sudo ip link set wlan0 down`, press each button | robot responds with no network |
| 8 | Watchdog | disconnect one switch, request that action | motor stops after the timeout, status shows `fault` |

If the motor never turns at all, check `EEP`/nSLEEP first: the DRV8833
tri-states its outputs until that pin is driven high, so a mis-wired sleep pin
looks exactly like a dead motor.

If the motor turns the wrong way, swap `OUT1` and `OUT2` rather than the sign
conventions in the code — interrogation must be the positive direction.

If step 3 never reverses, the switch wiring or polarity is wrong — check
`switch_event()` in `src/verbot/hardware/lgpio_switches.py` and confirm the pins
read low when closed.

If step 7 triggers the wrong action, reorder `BUTTON_ORDER` in
`src/verbot/hardware/mcp23017.py` to match the physical panel layout. The order
committed there is a guess.

## Values to measure and record

The defaults are inherited guesses. Replace them with measurements:

| Setting | Default | How to determine |
|---|---|---|
| `VERBOT_INTERROGATION_SPEED` | 85 | Bracketed from both sides: too slow and the drum stalls; too fast and it overshoots a switch before the motor finishes reversing, landing on the next one round instead. Find the lowest value that turns reliably, then back off further if actions land on the wrong switch. |
| `VERBOT_INTERROGATION_TIMEOUT_S` | 10.0 | Time a full drum revolution takes, roughly doubled. |
| `VERBOT_ACTION_SPEED` | -100 | Reduce if the mechanism sounds strained. Also cap it if the DRV8833's `VCC` is fed from 5V: the motor is a 3V part, so ±60 is roughly its rated voltage. |
| `VERBOT_MOTOR_SLEEP_PIN` | 6 | Set to `null` if the carrier's `J1` jumper is bridged — nSLEEP is then tied high in hardware and BCM 6 stays free. |

Record what you land on here once measured.

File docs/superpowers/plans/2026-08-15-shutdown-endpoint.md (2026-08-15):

# Shutdown Endpoint Implementation Plan

> **For agentic workers:** REQUIRED SUB-SKILL: Use superpowers:subagent-driven-development (recommended) or superpowers:executing-plans to implement this plan task-by-task. Steps use checkbox (`- [ ]`) syntax for tracking.

**Goal:** Add an opt-in, token-guarded `POST /system/shutdown` so the Pi can be powered down over HTTP without SSH and without the OnOff SHIM.

**Architecture:** A `SystemPower` protocol joins the existing `MotorDriver` / `SpeechEngine` / `Keypad` family, with a real adapter that shells out to `sudo -n poweroff` and a fake that records the call — so the suite keeps running off-Pi with no hardware and no root. The route is registered only when `shutdown_token` is configured, leaving today's API surface byte-identical for anyone who does not opt in.

**Tech Stack:** Python 3.13, FastAPI, pydantic-settings, pytest (asyncio auto mode), httpx `ASGITransport`. No new dependencies — `secrets` is stdlib and `BackgroundTasks` ships with FastAPI.

Spec: `docs/superpowers/specs/2026-08-15-shutdown-endpoint-design.md`

## Global Constraints

- **No new dependencies.** `pyproject.toml` must not gain a runtime or dev requirement.
- **The suite must keep running off-Pi**, with no hardware, no root, and no network. `uv run pytest -q` currently reports **81 passed**; it must still pass on a development laptop.
- **`build_power` returns `FakePower` whenever `settings.use_real_hardware` is false.** This is a safety property, not a convenience: without it, running the dev server on a laptop with a token configured would power off the laptop.
- **When `settings.shutdown_token` is `None` the route is not registered at all** — not registered-then-403. It must be absent from `/openapi.json`.
- **Token comparison uses `secrets.compare_digest`** on `bytes`, never `==`.
- TDD throughout: write the failing test, watch it fail, implement, watch it pass, commit.
- Ruff-clean under this repo's config: `select = ["E", "F", "I", "UP", "B"]`, `line-length = 100`. Verify with `uv run ruff check`.
- Match the surrounding code's voice. This codebase comments *why*, not *what*; docstrings explain the non-obvious. Do not add narration to self-evident lines.

## File Structure

| File | Responsibility |
|---|---|
| `src/verbot/hardware/protocols.py` | add `SystemPower` — the interface the API depends on |
| `src/verbot/hardware/system_power.py` | **new** — `SubprocessPower`, the only code that touches the OS |
| `src/verbot/hardware/fakes.py` | add `FakePower` |
| `src/verbot/main_support.py` | add `build_power(settings)` — real-vs-fake selection |
| `src/verbot/controller.py` | add `Controller.halt()` |
| `src/verbot/config.py` | add `shutdown_token` |
| `src/verbot/api.py` | widen `create_app`, register the route conditionally |
| `src/verbot/__main__.py` | build and inject `power` |
| `tests/test_main.py` | `build_power` selection tests |
| `tests/test_controller.py` | `halt()` tests |
| `tests/test_api.py` | endpoint tests, both fixtures |
| `docs/deployment.md` | sudoers rule, token generation, caveats |
| `README.md` | one line in Features |

---

### Task 1: SystemPower protocol, adapter, fake, and selection

**Files:**
- Modify: `src/verbot/hardware/protocols.py`
- Create: `src/verbot/hardware/system_power.py`
- Modify: `src/verbot/hardware/fakes.py`
- Modify: `src/verbot/main_support.py`
- Test: `tests/test_main.py`

**Interfaces:**
- Consumes: `Settings` from `verbot.config`
- Produces: `SystemPower` protocol with `async def shutdown(self) -> None`; `SubprocessPower()` (no constructor arguments); `FakePower()` exposing `shutdown_called: bool`; `build_power(settings: Settings) -> SystemPower`. Tasks 3 and 4 depend on all four names.

- [ ] **Step 1: Write the failing tests**

Append to `tests/test_main.py`. Add `FakePower` to the existing `verbot.hardware.fakes` import on line 6 and `build_power` to the existing `verbot.main_support` import on line 8.

```python
def test_build_power_returns_a_fake_when_hardware_disabled():
    """The dev server must never be able to power off a development laptop."""
    assert isinstance(build_power(Settings(use_real_hardware=False)), FakePower)

async def test_fake_power_records_the_request_instead_of_acting():
    power = FakePower()
    assert power.shutdown_called is False
    await power.shutdown()
    assert power.shutdown_called is True
```

- [ ] **Step 2: Run them to verify they fail**

Run: `uv run pytest tests/test_main.py -k power -v`
Expected: collection error — `ImportError: cannot import name 'FakePower'`.

- [ ] **Step 3: Add the protocol**

Append to `src/verbot/hardware/protocols.py`:

```python
class SystemPower(Protocol):
    """Power control for the machine the software runs on, not the robot."""

    async def shutdown(self) -> None:
        """Ask the operating system to power down. Returns once the request
        is issued, which is well before the machine actually stops."""
```

- [ ] **Step 4: Write the adapter**

Create `src/verbot/hardware/system_power.py`:

```python
"""Powering down the Pi itself.

The unit runs unprivileged, so this needs one narrow sudoers grant - see
docs/deployment.md. `-n` matters: without it, a missing grant makes sudo wait
for a password that nothing will ever type, and the request hangs instead of
failing.
"""

import asyncio
import logging

log = logging.getLogger(__name__)

POWEROFF_COMMAND = ("sudo", "-n", "poweroff")

class SubprocessPower:
    async def shutdown(self) -> None:
        log.warning("shutdown requested - powering off")
        try:
            proc = await asyncio.create_subprocess_exec(
                *POWEROFF_COMMAND,
                stdout=asyncio.subprocess.DEVNULL,
                stderr=asyncio.subprocess.DEVNULL,
            )
        except FileNotFoundError:
            log.error("sudo not found - cannot power off")
            return

        returncode = await proc.wait()
        if returncode != 0:
            log.error(
                "poweroff exited %d - check the sudoers grant in docs/deployment.md",
                returncode,
            )
```

- [ ] **Step 5: Write the fake**

Append to `src/verbot/hardware/fakes.py`, matching the style of `FakeSpeech` above it:

```python
class FakePower:
    def __init__(self) -> None:
        self.shutdown_called = False

    async def shutdown(self) -> None:
        self.shutdown_called = True
```

- [ ] **Step 6: Add the selection function**

Append to `src/verbot/main_support.py`:

```python
def build_power(settings: Settings) -> SystemPower:
    """Real power control on the Pi, a fake everywhere else.

    The fake is not just convenience: without this branch, a development
    machine running with a shutdown token configured would power itself off.
    """
    if not settings.use_real_hardware:
        from verbot.hardware.fakes import FakePower

        return FakePower()

    from verbot.hardware.system_power import SubprocessPower

    return SubprocessPower()
```

Add `SystemPower` to the existing `verbot.hardware.protocols` import on line 6 of that file.

- [ ] **Step 7: Run the tests to verify they pass**

Run: `uv run pytest tests/test_main.py -k power -v`
Expected: 2 passed.

- [ ] **Step 8: Run the full suite and lint**

Run: `uv run pytest -q && uv run ruff check`
Expected: 83 passed, `All checks passed!`

- [ ] **Step 9: Commit**

```bash
git add src/verbot/hardware/protocols.py src/verbot/hardware/system_power.py \
        src/verbot/hardware/fakes.py src/verbot/main_support.py tests/test_main.py
git commit -m "feat: SystemPower protocol with a subprocess adapter and fake"
```

---
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

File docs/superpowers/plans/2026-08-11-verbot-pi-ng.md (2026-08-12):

# verbot-pi-ng Implementation Plan

> **For agentic workers:** REQUIRED SUB-SKILL: Use superpowers:subagent-driven-development (recommended) or superpowers:executing-plans to implement this plan task-by-task. Steps use checkbox (`- [ ]`) syntax for tracking.

**Goal:** Control a Tomy Verbot toy robot from a Raspberry Pi Zero 2 W over an HTTP API, with speech output and a working front-panel keypad.

**Architecture:** A single `Controller` owns the interrogation/action state machine — the only piece carrying irreplaceable domain knowledge about the 1984 gearbox. All hardware sits behind `typing.Protocol` interfaces with in-memory fakes, so the entire state machine and API are tested on a dev machine with no Pi attached. Real hardware adapters (kernel PWM via sysfs, lgpio switch inputs, MCP23017
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

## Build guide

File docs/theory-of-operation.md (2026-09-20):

# Theory of Operation

How a 1984 Tomy Verbot works, what replaced its original electronics, and how
the software drives it.

The whole system rests on one fact about the toy: **Verbot has a single motor,
and its direction selects between two entirely different modes of operation.**
Everything else — the state machine, the API, the watchdog — follows from that.

---

## 1. The mechanism

A single bi-directional 3 V DC motor drives a planetary gear set. Motor polarity
chooses the mode:

| Motor direction | Mode | What happens |
|---|---|---|
| Anti-clockwise | **Interrogation** | A cam drum rotates, closing eight switches in a fixed repeating order. The robot does not visibly move. |
| Clockwise | **Action** | A clutch engages, the drum stops, and the gear set at whichever switch is closed performs its action. |

### Interrogation

The drum carries eight cams spaced around its circumference. As it turns, each
cam closes and then releases one of eight normally-open switches, always in the
same sequence:

> stop → rotate right → rotate left → forwards → reverse → put down → pick up → talk

The switches complete a circuit to ground, so the Pi reads them as GPIO inputs
with pull-ups: **closed reads LOW**. Interrogation is purely a selection phase —
it is the robot deciding *which* gear to engage, not doing anything.

### Action

Reversing the motor engages the clutch. The drum stops where it is, leaving the
last-selected switch held closed, and a shaft inside the drum begins to turn.
The planetary gear set at that position performs its action.

Two things follow, and they are the source of most of the software's design:

- **The selected switch stays closed for the duration of the action**, because
  the drum has stopped on its cam.
- **Nothing stops the action on its own.** The gear set runs until the motor is
  reversed again.

The exception is the two arm actions. `pick_up` and `put_down` have mechanical
**limit switches wired in series**. When an arm reaches the end of its travel
the circuit breaks — so the controller sees the switch *release* while the
action is running, and takes that as "finished". Without it the mechanism
strains against its own stop.

So the complete recipe for performing action X is:

> Run the motor anti-clockwise until switch X closes, then immediately reverse.

Full mechanical detail, the ribbon-cable colour map and the original power
arrangement are in [`hardware.md`](hardware.md).

---

## 2. The electronics

The original 1980s control board is removed. The motor, gearbox, interrogation
switch bank and front keypad are retained and driven directly from the Pi.

| Part | Role | Notes |
|---|---|---|
| **Raspberry Pi Zero 2 W** | Everything | 64-bit Raspberry Pi OS (Trixie) |
| **DRV8833** carrier | Motor driver | Replaces the original polarity-reversing circuit |
| **MAX98357A** | I2S DAC + amplifier | Speech output to a passive 4–8 Ω speaker |
| **MCP23017** | I2C GPIO expander | The eight front-panel buttons and the status LED |
| **Pimoroni OnOff SHIM** | Power button, clean shutdown | Not fitted on this build; BCM 17 is reassigned to the ready-pin LED - see `hardware.md` |
| USB power bank | 5 V supply | The original 3 V and 6 V battery rails are gone |

Four deliberate choices are worth knowing, because they constrain everything
else:

**Motor PWM is kernel-managed, not pigpio.** The DRV8833 has no PHASE/ENABLE
mode, so direction is expressed by *which* of `IN1`/`IN2` carries the PWM while
the other sits low — meaning both inputs need their own PWM channel
(`dtoverlay=pwm-2chan` on BCM 12 and 13). pigpio would need the PCM peripheral
for DMA timing, and the I2S DAC needs PCM too. Kernel PWM has no such conflict,
so this robot gets both hardware PWM *and* audio. The original project had to
give up hardware PWM for exactly this reason.

**The Pi supplies signals, not motor power.** `IN1`/`IN2` are high-impedance
inputs drawing microamps; the motor current comes from the DRV8833's own `VCC`
feed and never touches a GPIO. See
[Powering the motor](hardware.md#powering-the-motor).

**The eight interrogation switches are direct GPIO inputs**, edge-triggered via
`lgpio` with internal pull-ups. They are not on the expander — latency matters
for catching a cam as the drum sweeps past.

**The front panel is on I²C**, because eight more direct GPIOs were not
available. This is the one part that is not latency-critical: it is polled.

Pin assignments are in [`hardware.md`](hardware.md#gpio-assignments-this-project);
the schematic is at [`../hardware/verbot-schematic.pdf`](../hardware/verbot-schematic.pdf).

---

## 3. The software

Four layers, each testable without a Raspberry Pi:

```mermaid
flowchart TD
    subgraph inputs [Inputs]
        HTTP[HTTP API / web page]
        PANEL[Front panel keypad]
    end
    CTRL[Controller<br/>interrogation/action state machine]
    subgraph hw [Hardware layer - Protocol + adapter + fake]
        MOTOR[MotorDriver<br/>kernel PWM sysfs]
        SW[SwitchBank<br/>lgpio edge alerts]
        SPEECH[SpeechEngine<br/>espeak-ng]
        KEY[Keypad / StatusLed<br/>MCP23017]
    end
    HTTP --> CTRL
    PANEL --> CTRL
    CTRL --> MOTOR
    SW -- switch events --> CTRL
    HTTP --> SPEECH
    KEY --> PANEL
```

**The hardware layer** is a set of `Protocol` classes in
`hardware/protocols.py` — `MotorDriver`, `SwitchBank`, `Keypad`, `StatusLed`,
`SpeechEngine`, `SystemPower`. Each has a real adapter and an in-memory fake.
`VERBOT_USE_REAL_HARDWARE=false` (the default) selects the fakes, which is why
the entire test suite runs on any machine.

**The controller** (`controller.py`) is the state machine and owns all robot
behaviour. It is the only thing that talks to the motor.

**The API** (`api.py`) is a thin FastAPI layer. It validates and delegates; it
holds no robot logic.

**The front panel feeds the same funnel.** The keypad's listener signature is
exactly `controller.request_action`, so a button press and an HTTP request are
indistinguishable downstream — and the panel keeps working with no network.

### The state machine

```mermaid
stateDiagram-v2
    [*] --> IDLE
    IDLE --> INTERROGATING: request_action(X)
    ACTING --> INTERROGATING: request_action(Y)
    INTERROGATING --> ACTING: switch X closes<br/>(motor reverses)
    INTERROGATING --> IDLE: switch STOP closes
    INTERROGATING --> FAULT: watchdog timeout
    ACTING --> INTERROGATING: limit switch releases<br/>(arm actions only)
    ACTING --> IDLE: halt()
    INTERROGATING --> IDLE: halt()
    FAULT --> INTERROGATING: request_action(X)
```

Requesting an action sets the motor to `+interrogation_speed` and starts a
watchdog. Two switch events matter, and the mode disambiguates them:

- `INTERROGATING` + **closed** + it is the one we want → the gears are in
  position; reverse to `action_speed`.
- `ACTING` + **released** + it is the action we are running → a limit switch
  broke the circuit; the action is finished, so park at the stop cam.

Everything else is the drum sweeping past, and is ignored.

**The watchdog guards interrogation only.** If the expected switch never
arrives within `interrogation_timeout_s`, the controller stops the motor and
enters `FAULT` — this is what stops the robot grinding away when a switch is
mis-wired. There is deliberately **no timeout on `ACTING`**, because a running
action is supposed to continue until commanded otherwise. For `forwards` and
friends that means the operator ends it; only the arm actions stop themselves.

### Two ways to stop

These are different operations and the distinction matters:

| | Endpoint | Effect |
|---|---|---|
| **Halt** | `POST /halt` | Motor off immediately. Drum left wherever it is, position unknown. |
| **Stop** | `POST /actions/stop` | Interrogates round to the stop cam and parks there, then off. |

`/halt` is the emergency control — it is what the oversized red button on the
web page calls, and what runs before a shutdown. `/actions/stop` is the tidy
one: it homes the mechanism so the next interrogation starts from a known
position.

### Speech

`espeak-ng` is deliberate: tiny, no model files, comfortable on a Zero 2 W, and
its clipped synthetic voice suits a 1984 toy far better than a neural TTS would.
Calls are serialised behind a lock — one sound card, one voice at a time.

Speaking can optionally drive the mouth. `POST /say` with `animate: true`
interrogates for `TALK`, **waits until the gear is actually engaged**, speaks,
then parks at the stop cam. The wait matters: interrogation takes seconds, so
starting the phrase when the request is accepted would play the audio before the
mouth moved. If the gear never engages the failure is logged and the phrase is
spoken anyway — the audio is the point, and refusing to speak because the
gearbox is absent would make the speaker untestable.

---

## 4. The API

Interactive docs are served at `/docs`, and a control page for bring-up at `/`.

| Method | Path | Purpose |
|---|---|---|
| `GET` | `/` | Web control page: buttons, status, speak box, speed sliders, log, and shutdown when configured |
| `GET` | `/healthz` | Liveness. `{"status": "ok"}` |
| `GET` | `/status` | Current `mode`, `current_action`, `desired_action` |
| `POST` | `/actions/{action}` | Interrogate for `action`, then perform it |
| `POST` | `/stop` | Park the drum at the stop cam |
| `POST` | `/halt` | Cut the motor now, without interrogating |
| `POST` | `/say` | Speak text, optionally animating the mouth |
| `GET` | `/speeds` | Current interrogation and action speeds |
| `PATCH` | `/speeds` | Adjust either speed live (not persisted) |
| `POST` | `/system/shutdown` | Power off. Registered **only** when enabled |

`{action}` is one of `stop`, `rotate_right`, `rotate_left`, `forwards`,
`reverse`, `put_down`, `pick_up`, `talk`. It is typed as an enum, so an unknown
action is a `422` rather than a silently ignored request.

Action endpoints return `202 Accepted` with the controller status: they return
once the motor *starts*, not once the action completes. Poll `/status` to follow
progress.

```bash
curl -s localhost:8080/status
curl -X POST localhost:8080/actions/pick_up
curl -X POST localhost:8080/halt
curl -X POST localhost:8080/say \
  -H 'content-type: application/json' \
  -d '{"text": "I am Verbot", "animate": true}'
curl -X PATCH localhost:8080/speeds \
  -H 'content-type: application/json' \
  -d '{"interrogation_speed": 40}'
```

The robot advertises itself over mDNS as `verbot.local`, so the API is reachable
without knowing its address.

### Shutdown

`/system/shutdown` exists only if `VERBOT_SHUTDOWN_ENABLED=true` — the default
deployment has no such route at all, rather than a route that always refuses.
It is unauthenticated, same as the rest of the API: anything on the LAN that
can already drive the robot can also power it off, which is the same trust
boundary as everywhere else in this project. It halts the motor before the
machine goes, and returns `202` from a background task so the response
outlives the poweroff.

The web page grows a **Shut down the Pi** control when the endpoint is
enabled, and omits it entirely otherwise. Clicking it asks for confirmation in
the browser (`confirm()`) before sending the request - a guard against a
misclick, not against a hostile network.

---

## 5. Configuration

Every setting is an environment variable prefixed `VERBOT_`, readable from a
`.env` file in the working directory. The ones that change behaviour most:

| Variable | Default | Effect |
|---|---|---|
| `VERBOT_USE_REAL_HARDWARE` | `false` | **`true` on the robot.** False runs entirely on fakes and nothing moves. |
| `VERBOT_KEYPAD_ENABLED` | `true` | `false` skips the MCP23017 entirely — useful before it is wired |
| `VERBOT_INTERROGATION_SPEED` | `85` | Drum speed. Bracketed from both sides - too slow stalls the drum, too fast overshoots a switch before the motor finishes reversing and lands on the next one round. |
| `VERBOT_ACTION_SPEED` | `-100` | Negative by convention. Cap it if `VCC` is 5 V — the motor is a 3 V part. |
| `VERBOT_INTERROGATION_TIMEOUT_S` | `10.0` | Watchdog. Roughly double a full drum revolution. |
| `VERBOT_STARTUP_ANNOUNCEMENT` | `"I am Verbot! …"` | Spoken once ready. Empty to stay silent. |
| `VERBOT_SHUTDOWN_ENABLED` | `false` | `true` registers `/system/shutdown` |

Speeds are signed: **positive is interrogation, negative is action.** If the
motor turns the wrong way, swap `OUT1` and `OUT2` rather than the signs in the
code.

---

## Further reading

- [`hardware.md`](hardware.md) — pin assignments, ribbon colours, wiring warnings
- [`deployment.md`](deployment.md) — flashing, first boot, install, bring-up checklist
- [`../hardware/verbot-schematic.pdf`](../hardware/verbot-schematic.pdf) — full schematic

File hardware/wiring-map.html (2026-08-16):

Tomy Verbot × Raspberry Pi Zero 2 W

# Verbot Wiring Map

Every connection between the 1984 gearbox, the four breakout boards, and the Pi's 40-pin header — with the interrogation ribbon drawn in the colours you'll actually be holding.

Header 40-pin, Pi Zero 2 W Free after build BCM 5, 14, 15, 20, 23, 24 Source of truth src/verbot/config.py

## System map what talks to what

Five boards hang off the Pi. Only the gearbox is original 1984 hardware — everything else replaces the controller board that was removed.

Signal directions matter. The gearbox only ever reports position back to the Pi; it takes no commands. Everything the robot actually does happens through the DRV8833, which reverses one motor to switch the whole mechanism between hunting for a gear and running it.

## The interrogation ribbon 9-core, gearbox → Pi

A drum inside the gearbox turns eight cams past eight normally-open switches. Each closes in a fixed sequence, telling the software which gear set is currently selected. All eight return through the single white ground.

The two switches drawn with a break are the important ones. Brown and orange pass through mechanical limit switches inside the gearbox. When an arm reaches the end of its travel that circuit opens — the controller sees the switch release mid-action and stops the motor. Without that signal the mechanism strains against its own stop.

How an action actually runs. Drive the motor anti-clockwise until the switch for the action you want closes, then immediately reverse it. That engages a clutch: the drum stops, and a shaft inside it starts turning the selected gear set. Direction alone chooses between hunting and doing.

## Power tree one rail, one known compromise

A single 5V bank feeds everything through the OnOff SHIM's load switch. That includes the motor, which is the part worth thinking about.

The thick line is the compromise. Motor current runs through the SHIM's load switch, rated around 2 A. A 3 V motor stalled on a 5 V rail can transiently exceed that, and the failure looks like a software hang — the Pi simply drops mid-action.

#### Two things that will bite you

Cap the action speed. The motor is a 3 V part sitting on a 5 V rail. Keep VERBOT_ACTION_SPEED near ±60 rather than ±100, or you are overdriving it every time it moves.

Never feed VCC from the Pi's 3V3 pin to get a nominal 3 V. That rail comes off the PMIC and cannot supply a stalled motor. VCC is the motor supply, not a logic rail — whatever you apply is what the motor sees.

## Board by board every remaining connection

### DRV8833 carrier

Carrier | Goes to | BCM
VCC | +5V motor rail | —
GND | Common ground | —
IN1 | pin 32 | 12 · PWM0
IN2 | pin 33 | 13 · PWM1
EEP | pin 31 | 6
ULT | pin 36 | 16
OUT1 / OUT2 | Verbot motor | —
IN3 · IN4 · OUT3 · OUT4 | unused, channel B | —

### MAX98357A

Board | Goes to | BCM
VIN | +5V | —
GND | Common ground | —
BCLK | pin 12 | 18
LRC | pin 35 | 19
DIN | pin 40 | 21
+ / − | 4–8 Ω passive speaker | —
SD | leave floating | —
GAIN | floating = 9 dB | —

### MCP23017 · address 0x20

Board | Goes to | BCM
VDD | pin 1 · +3V3 | —
VSS | Common ground | —
SDA | pin 3 | 2
SCL | pin 5 | 3
RESET | +3V3, held high | —
A0 · A1 · A2 | GND → 0x20 | —
GPA0–GPA7 | 8 panel buttons → GND | —
GPB0 | 330 Ω → status LED → GND | —
INTA · INTB | unused, polled at 50 Hz | —

### OnOff SHIM

Board | Goes to | BCM
USB 5V in | Power bank | —
5V out | pins 2 · 4 | —
BTN | pin 11 | 17
LED | pin 13 | 27
POWEROFF | pin 7 | 4

### Ground & rails

Rail | Header pins
+5V | 2 · 4
+3V3 | 1 · 17
GND | 6 · 9 · 14 · 20 · 25 · 30 · 34 · 39

## Front panel the part that isn't confirmed

The eight original red buttons map one-to-one onto the eight gearbox actions, exactly as the toy did in 1984. They hang off the expander's port A as active-low inputs with pull-ups enabled.

Left-to-right panel order, as assumed by BUTTON_ORDER
Expander pin | Button | Expander pin | Button
GPA0 | Stop | GPA4 | Rotate right
GPA1 | Forwards | GPA5 | Pick up
GPA2 | Reverse | GPA6 | Put down
GPA3 | Rotate left | GPA7 | Talk

#### Verify before you wire this

This assumes the eight buttons are independent switches to a common rail. That has never been confirmed on the real panel — they may well be a matrix. Check with a meter first.

The original PCB also carried the power switching for both battery rails, so the cleanest approach is to bypass that board entirely and solder to the switch contacts directly.

The button order above is a guess. If a button triggers the wrong action at bring-up, reorder BUTTON_ORDER rather than rewiring.

Pin assignments come from src/verbot/config.py and src/verbot/hardware/mcp23017.py; the mechanical analysis and ribbon colour map were reverse-engineered by Neil Davis for neildavis/verbot-pi, partly from Tomy's patent US4717364A. The formal schematic lives at hardware/verbot-schematic.pdf — this page is its readable companion, not a replacement.

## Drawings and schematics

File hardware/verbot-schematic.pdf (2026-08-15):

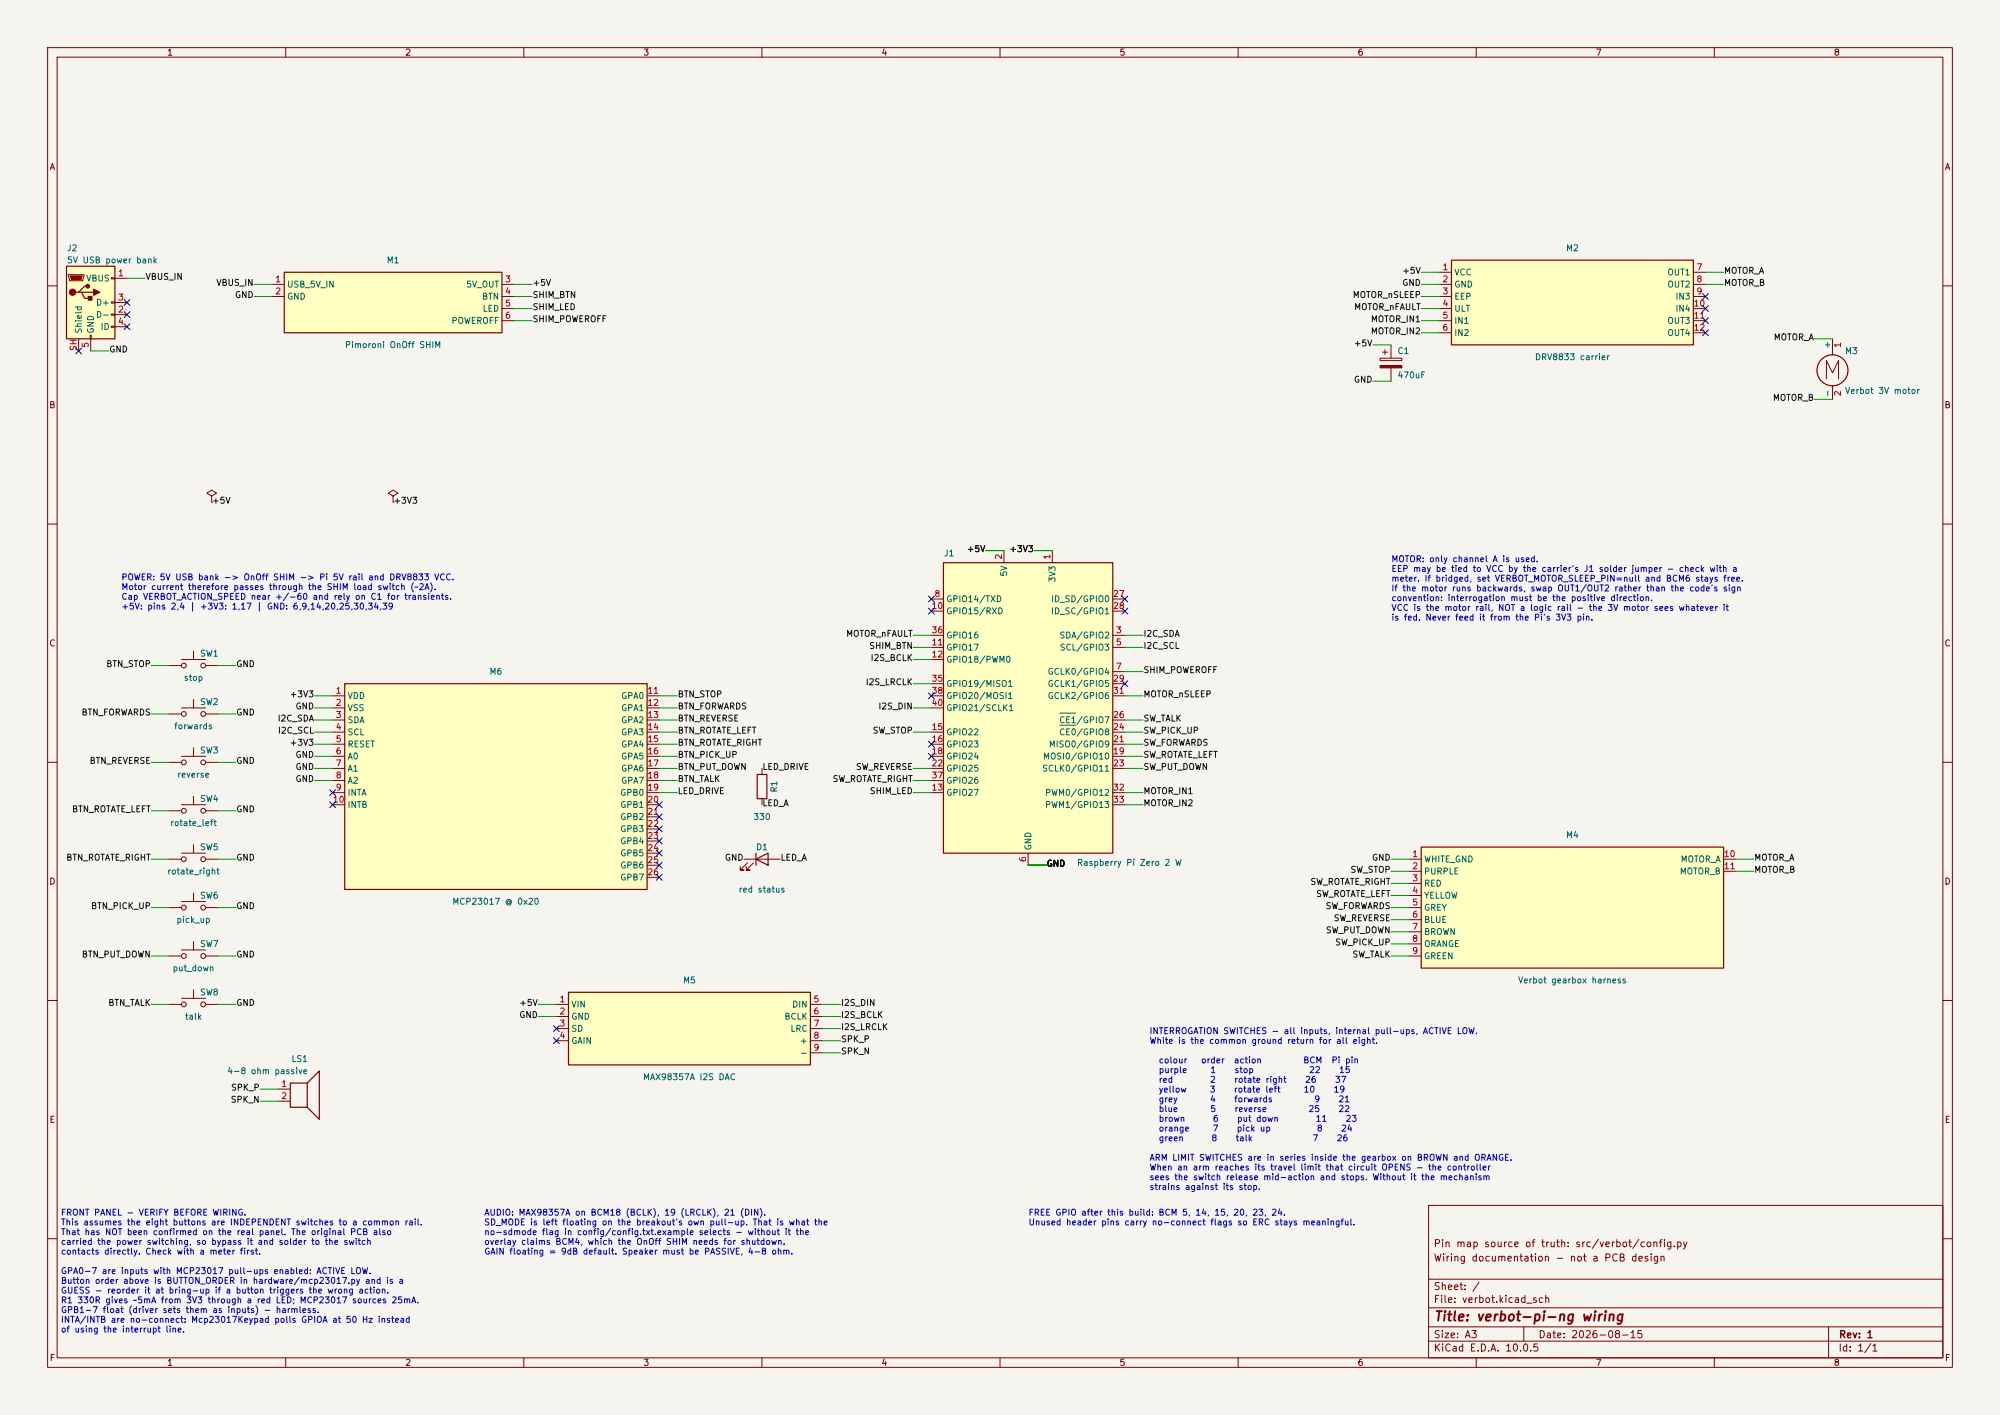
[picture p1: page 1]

MOTOR: only channel A is used. EEP may be tied to VCC by the carrier's J1 solder jumper - check with a meter. If bridged, set VERBOT_MOTOR_SLEEP_PIN=null and BCM6 stays free.

is fed. Never feed it from the Pi's 3V3 pin. POWER: 5V USB bank -> OnOff SHIM -> Pi 5V rail and DRV8833 VCC. Motor current therefore passes through the SHIM load switch (~2A).

If the motor runs backwards, swap OUT1/OUT2 rather than the code's sign
convention: interrogation must be the positive direction. VCC is the motor rail, NOT a logic rail - the 3V motor sees whatever it

Cap VERBOT_ACTION_SPEED near +/-60 and rely on C1 for transients. +5V: pins 2,4 | +3V3: 1,17 | GND: 6,9,14,20,25,30,34,39

ARM LIMIT SWITCHES are in series inside the gearbox on BROWN and ORANGE. When an arm reaches its travel limit that circuit OPENS - the controller sees the switch release mid-action and stops. Without it the mechanism

strains against its stop.

FREE GPIO after this build: BCM 5, 14, 15, 20, 23, 24. Unused header pins carry no-connect flags so ERC stays meaningful. AUDIO: MAX98357A on BCM18 (BCLK), 19 (LRCLK), 21 (DIN). SD_MODE is left floating on the breakout's own pull-up. That is what the no-sdmode flag in config/config.txt.example selects - without it the overlay claims BCM4, which the OnOff SHIM needs for shutdown. GAIN floating = 9dB default. Speaker must be PASSIVE, 4-8 ohm. FRONT PANEL - VERIFY BEFORE WIRING. This assumes the eight buttons are INDEPENDENT switches to a common rail. That has NOT been confirmed on the real panel. The original PCB also

carried the power switching, so bypass it and solder to the switch
contacts directly. Check with a meter first. GPA0-7 are inputs with MCP23017 pull-ups enabled: ACTIVE LOW. Button order above is BUTTON_ORDER in hardware/mcp23017.py and is a GUESS - reorder it at bring-up if a button triggers the wrong action. R1 330R gives ~5mA from 3V3 through a red LED; MCP23017 sources 25mA. GPB1-7 float (driver sets them as inputs) - harmless.

Pin map source of truth: src/verbot/config.py
Wiring documentation - not a PCB design

Sheet: /
File: verbot.kicad_sch
Title: verbot-pi-ng wiring

INTA/INTB are no-connect: Mcp23017Keypad polls GPIOA at 50 Hz instead
of using the interrupt line.

Size: A3 | Rev: 1 | F Date: 2026-08-15
KiCad E.D.A. 10.0.5 | Id: 1/1

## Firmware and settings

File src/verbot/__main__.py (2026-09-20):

"""Entrypoint. Wires hardware, controller, API and mDNS together."""

import asyncio
import contextlib
import logging

import uvicorn
from fastapi import FastAPI

from verbot.api import create_app
from verbot.config import Settings
from verbot.controller import Controller
from verbot.discovery import ServiceAdvertiser
from verbot.hardware.protocols import LedPattern
from verbot.main_support import build_hardware, build_keypad, build_power, build_ready_signal
from verbot.speech import EspeakEngine

log = logging.getLogger(__name__)


async def announce(speech: EspeakEngine, text: str) -> None:
    """Speak the readiness greeting.

    Runs detached from startup: the phrase takes a couple of seconds, and the
    API and front panel should not wait on the sound card to become useful.
    A failure here is cosmetic, so it is logged rather than propagated.
    """
    try:
        await speech.say(text)
    except Exception:
        log.exception("startup announcement failed")


def build_app(settings: Settings) -> FastAPI:
    motor, switches = build_hardware(settings)
    controller = Controller(motor=motor, switches=switches, settings=settings)
    keypad, led = build_keypad(settings)
    power = build_power(settings)
    ready_signal = build_ready_signal(settings)
    speech = EspeakEngine(settings)
    advertiser = ServiceAdvertiser(settings)

    @contextlib.asynccontextmanager
    async def lifespan(app: FastAPI):
        await controller.start()
        if keypad is not None:
            # The button listener signature is exactly request_action's, so the
            # front panel feeds the same funnel as the API with no adapter.
            keypad.set_listener(controller.request_action)
            await keypad.start()
        if led is not None:
            await led.set_pattern(LedPattern.SOLID)
        await advertiser.start()
        # Last, so "ready" means the controller, panel and mDNS are all up.
        if ready_signal is not None:
            await ready_signal.set_ready(True)
        announcement: asyncio.Task[None] | None = None
        if settings.startup_announcement:
            announcement = asyncio.create_task(announce(speech, settings.startup_announcement))
        app.state.announcement = announcement
        try:
            yield
        finally:
            # First, so nothing watching the pin thinks the robot still works
            # while the rest of shutdown is still in flight.
            if ready_signal is not None:
                await ready_signal.close()
            # Order matters: stop advertising, then guarantee the motor is off.
            if announcement is not None:
                announcement.cancel()
                with contextlib.suppress(asyncio.CancelledError):
                    await announcement
            await advertiser.close()
            if led is not None:
                await led.set_pattern(LedPattern.OFF)
                await led.close()
            if keypad is not None:
                await keypad.close()
            await controller.close()
            await speech.close()

    app = create_app(
        controller=controller,
        speech=speech,
        settings=settings,
        power=power,
        ready_signal=ready_signal,
    )
    app.router.lifespan_context = lifespan
    # Expose the composed hardware for introspection and tests.
    app.state.motor = motor
    app.state.switches = switches
    app.state.keypad = keypad
    app.state.led = led
    app.state.power = power
    app.state.ready_signal = ready_signal
    return app


def main() -> None:
    logging.basicConfig(
        level=logging.INFO,
        format="%(asctime)s %(levelname)-7s %(name)s: %(message)s",
    )
    settings = Settings()
    uvicorn.run(build_app(settings), host=settings.host, port=settings.port, log_config=None)


if __name__ == "__main__":
    main()

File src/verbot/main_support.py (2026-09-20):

"""Hardware selection, split out from __main__ so it is importable in tests."""

import logging

from verbot.config import Settings
from verbot.hardware.protocols import (
    Keypad,
    MotorDriver,
    ReadySignal,
    StatusLed,
    SwitchBank,
    SystemPower,
)

log = logging.getLogger(__name__)


def build_hardware(settings: Settings) -> tuple[MotorDriver, SwitchBank]:
    """Return real adapters on the Pi, fakes everywhere else.

    The lgpio imports live inside this branch so dev machines never need them.
    """
    if not settings.use_real_hardware:
        from verbot.hardware.fakes import FakeMotor, FakeSwitchBank

        log.warning("VERBOT_USE_REAL_HARDWARE is false - running on fake hardware")
        return FakeMotor(), FakeSwitchBank()

    from verbot.hardware.lgpio_switches import LgpioSwitchBank
    from verbot.hardware.pwm_motor import KernelPwmMotor

    return KernelPwmMotor(settings), LgpioSwitchBank(settings)


def build_keypad(settings: Settings) -> tuple[Keypad | None, StatusLed | None]:
    """Return (keypad, led), or (None, None) when the keypad is disabled."""
    if not settings.keypad_enabled:
        return None, None

    if not settings.use_real_hardware:
        from verbot.hardware.fakes import FakeKeypad, FakeLed

        return FakeKeypad(), FakeLed()

    from verbot.hardware.mcp23017 import Mcp23017Keypad, Mcp23017Led, open_bus

    bus = open_bus(settings)
    return Mcp23017Keypad(settings, bus=bus), Mcp23017Led(settings, bus=bus)


def build_power(settings: Settings) -> SystemPower:
    """Real power control on the Pi, a fake everywhere else.

    The fake is not just convenience: without this branch, a development
    machine running with a shutdown token configured would power itself off.
    """
    if not settings.use_real_hardware:
        from verbot.hardware.fakes import FakePower

        return FakePower()

    from verbot.hardware.system_power import SubprocessPower

    return SubprocessPower()


def build_ready_signal(settings: Settings) -> ReadySignal | None:
    """Return the readiness-pin adapter, or None if no pin is configured."""
    if settings.ready_pin is None:
        return None

    if not settings.use_real_hardware:
        from verbot.hardware.fakes import FakeReadySignal

        return FakeReadySignal()

    from verbot.hardware.ready_pin import LgpioReadySignal

    return LgpioReadySignal(settings)

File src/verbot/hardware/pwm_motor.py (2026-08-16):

"""Motor driver: two kernel hardware PWM channels (sysfs) driving a DRV8833.

Requires `dtoverlay=pwm-2chan,pin=12,func=4,pin2=13,func2=4` in
/boot/firmware/config.txt, which exposes /sys/class/pwm/pwmchip0 with channels
0 and 1.

The DRV8833 has no MODE pin and therefore no PHASE/ENABLE mode: direction is
expressed by *which* of IN1/IN2 carries the PWM while the other sits low, not
by a separate direction level. So both inputs need a PWM channel. Driving one
input high and PWMing the other would give slow-decay braking instead; fast
decay is used here because it keeps the mapping from duty cycle to speed
monotonic, which matters for finding the lowest reliable interrogation speed.

Kernel PWM is used instead of pigpio because pigpio needs the PCM peripheral
for DMA timing in order to leave hardware PWM free - and the I2S DAC needs PCM.
The kernel PWM driver has no such conflict, so the robot gets both true 250 kHz
PWM and audio. The original project had to abandon hardware PWM for exactly
this reason.
"""

import asyncio
import logging
import os
from pathlib import Path
from typing import Any

from verbot.config import Settings

log = logging.getLogger(__name__)

DEFAULT_SYSFS_ROOT = Path("/sys/class/pwm")

# How long to wait for the kernel to create the channel directory after export.
EXPORT_POLL_INTERVAL_S = 0.01
EXPORT_POLL_ATTEMPTS = 50

# How long to wait for udev to hand the exported channel to the gpio group.
# Longer than the export wait: udev runs a shell helper (99-com.rules) rather
# than just materialising a directory, and it is competing with everything else
# starting at boot.
ACCESS_POLL_ATTEMPTS = 200

# nSLEEP is active low: high wakes the driver, low tri-states the outputs.
AWAKE = 1
ASLEEP = 0

# nFAULT is open-drain, active low, and needs the input's pull-up to read high.
FAULT_LEVEL = 0


class KernelPwmMotor:
    def __init__(
        self,
        settings: Settings,
        sysfs_root: Path = DEFAULT_SYSFS_ROOT,
        gpio: Any | None = None,
    ) -> None:
        self._settings = settings
        self._chip = sysfs_root / f"pwmchip{settings.pwm_chip}"
        # Channel A is IN1 (positive speeds), channel B is IN2 (negative).
        self._channel_a = settings.pwm_channel_a
        self._channel_b = settings.pwm_channel_b
        self._gpio = gpio

    def _path(self, channel: int) -> Path:
        return self._chip / f"pwm{channel}"

    async def open(self) -> None:
        for channel in (self._channel_a, self._channel_b):
            await self._export(channel)
            path = self._path(channel)
            # Duty before period: the kernel rejects a duty longer than the period.
            self._write(path / "duty_cycle", "0")
            self._write(path / "period", str(self._settings.pwm_period_ns))
            self._write(path / "enable", "1")

        if self._gpio is None:
            self._gpio = self._claim_pins()

        if self._settings.motor_sleep_pin is not None:
            self._gpio.write(self._settings.motor_sleep_pin, AWAKE)

        log.info(
            "motor ready: %s channels %d/%d at %d ns period",
            self._chip,
            self._channel_a,
            self._channel_b,
            self._settings.pwm_period_ns,
        )

    async def _export(self, channel: int) -> None:
        path = self._path(channel)
        if not path.exists():
            self._write(self._chip / "export", str(channel))
            # The kernel creates the channel directory asynchronously.
            for _ in range(EXPORT_POLL_ATTEMPTS):
                if path.exists():
                    break
                await asyncio.sleep(EXPORT_POLL_INTERVAL_S)
            else:
                raise RuntimeError(f"PWM channel {path} did not appear after export")

        await self._await_writable(path / "duty_cycle")

    async def _await_writable(self, path: Path) -> None:
        """Wait for udev to hand the freshly exported channel to the gpio group.

        The kernel creates pwmN root-owned; 99-com.rules then runs `chgrp -R
        gpio` over the pwm subsystem asynchronously. Existence therefore does
        not imply writability, and the first start after a boot loses that race
        and dies with EACCES on duty_cycle. Restart=on-failure papers over it a
        few seconds later, which makes the fault look intermittent.
        """
        for _ in range(ACCESS_POLL_ATTEMPTS):
            if os.access(path, os.W_OK):
                return
            await asyncio.sleep(EXPORT_POLL_INTERVAL_S)
        raise RuntimeError(
            f"{path} never became writable. Is this user in the gpio group, and does "
            "99-com.rules chgrp the pwm subsystem?"
        )

    def _claim_pins(self) -> "_LgpioPins":
        import lgpio

        handle = lgpio.gpiochip_open(0)
        if self._settings.motor_sleep_pin is not None:
            lgpio.gpio_claim_output(handle, self._settings.motor_sleep_pin, ASLEEP)
        if self._settings.motor_fault_pin is not None:
            lgpio.gpio_claim_input(handle, self._settings.motor_fault_pin, lgpio.SET_PULL_UP)
        return _LgpioPins(handle)

    async def set_speed_percent(self, percent: int) -> None:
        if not -100 <= percent <= 100:
            raise ValueError(f"speed {percent} out of range [-100, 100]")

        duty_ns = self._settings.pwm_period_ns * abs(percent) // 100
        if percent < 0:
            active, idle = self._channel_b, self._channel_a
        else:
            active, idle = self._channel_a, self._channel_b

        # Idle first. Both inputs driven at once is a brake, not a direction,
        # and passing through it on every reversal shocks the gearbox.
        self._write(self._path(idle) / "duty_cycle", "0")
        self._write(self._path(active) / "duty_cycle", str(duty_ns))

    async def read_fault(self) -> bool:
        """True while the DRV8833 reports overcurrent, overtemp or undervoltage.

        Latched by the chip until nSLEEP is toggled or the fault clears.
        """
        if self._settings.motor_fault_pin is None or self._gpio is None:
            return False
        return self._gpio.read(self._settings.motor_fault_pin) == FAULT_LEVEL

    async def close(self) -> None:
        for channel in (self._channel_a, self._channel_b):
            try:
                # Zero the duty before disabling; a latched duty can twitch the motor.
                self._write(self._path(channel) / "duty_cycle", "0")
                self._write(self._path(channel) / "enable", "0")
            except OSError as exc:
                log.warning("could not cleanly stop PWM channel %d: %s", channel, exc)

        if self._gpio is not None:
            if self._settings.motor_sleep_pin is not None:
                self._gpio.write(self._settings.motor_sleep_pin, ASLEEP)
            self._gpio.close()

    def _write(self, path: Path, value: str) -> None:
        path.write_text(value)
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

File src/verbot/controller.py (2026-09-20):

"""The Verbot interrogation/action state machine.

Verbot has one bi-directional motor. Running it anti-clockwise rotates a cam
drum that closes each of eight switches in turn (interrogation). Reversing to
clockwise stops the drum and drives the gear set at whichever switch is closed
(action). So performing action X means: interrogate until X closes, then
reverse. See docs/hardware.md.
"""

import asyncio
import logging

from verbot.actions import ACTIONS_WITH_LIMIT_SWITCH, Action, ControllerStatus, Mode
from verbot.config import Settings
from verbot.hardware.protocols import MotorDriver, SwitchBank

log = logging.getLogger(__name__)


class Controller:
    def __init__(
        self,
        motor: MotorDriver,
        switches: SwitchBank,
        settings: Settings,
    ) -> None:
        self._motor = motor
        self._switches = switches
        self._settings = settings
        self._mode = Mode.IDLE
        self._current: Action | None = None
        self._desired: Action | None = None
        self._timeout_task: asyncio.Task[None] | None = None
        # Pulsed on every mode change so callers can await a transition rather
        # than poll the status property.
        self._changed = asyncio.Event()

    async def start(self) -> None:
        await self._motor.open()
        self._switches.set_listener(self.handle_switch_event)
        await self._switches.start()
        await self._motor.set_speed_percent(0)

    async def close(self) -> None:
        self._cancel_timeout()
        await self._motor.set_speed_percent(0)
        await self._motor.close()
        await self._switches.close()

    async def halt(self) -> None:
        """Cut the motor now, without running an action.

        Deliberately not Action.STOP: that interrogates for the stop cam and
        takes seconds of movement. This is for the moment before the machine
        powers off, when the robot should simply stop.

        `_current` is trustworthy only when the drum is stationary at a known
        cam: true in ACTING (the drum is parked at the cam it names; only the
        gear set was running) and in IDLE (parked, having arrived via a
        switch event), so it is left alone in both. Whenever the drum was
        moving - INTERROGATING mid-sweep, or FAULT, which is only ever
        entered from the watchdog firing during INTERROGATING - `_current`
        still names the *previous* cam, not wherever the drum stopped, so it
        is cleared to the same "position unknown" state it carries at boot.
        Getting this wrong makes request_action() believe a later STOP is
        already satisfied and skip it entirely.
        """
        if self._mode not in (Mode.ACTING, Mode.IDLE):
            self._current = None
        self._cancel_timeout()
        self._mode = Mode.IDLE
        self._notify()
        self._desired = None
        await self._motor.set_speed_percent(0)

    @property
    def status(self) -> ControllerStatus:
        return ControllerStatus(
            mode=self._mode,
            current_action=self._current,
            desired_action=self._desired,
        )

    def _notify(self) -> None:
        self._changed.set()
        self._changed.clear()

    async def wait_until_acting(self, action: Action, timeout: float) -> bool:
        """Block until `action` is actually running. False if it never gets there.

        Speech has to start when the mouth starts moving, not when the request
        is accepted — interrogation takes seconds, and can fault. Returns False
        on fault or timeout rather than raising: a still mouth is a reason to
        speak anyway, not to abandon the phrase.
        """
        loop = asyncio.get_running_loop()
        deadline = loop.time() + timeout
        while True:
            if self._mode is Mode.ACTING and self._current is action:
                return True
            if self._mode is Mode.FAULT:
                return False
            remaining = deadline - loop.time()
            if remaining <= 0:
                return False
            try:
                await asyncio.wait_for(self._changed.wait(), timeout=remaining)
            except TimeoutError:
                return False

    async def request_action(self, action: Action) -> None:
        """Begin interrogating for `action`. Returns as soon as the motor starts."""
        if self._mode is Mode.ACTING and action is self._current:
            log.debug("%s already running, ignoring request", action)
            return
        # Only skip a STOP if we know the drum is already parked there. At boot
        # `_current` is None: the motor is off but the drum position is
        # unknown, so an explicit stop still homes the mechanism.
        if self._mode is Mode.IDLE and action is Action.STOP and self._current is Action.STOP:
            log.debug("already parked at stop, ignoring request")
            return

        log.info("interrogating for %s", action)
        self._desired = action
        self._mode = Mode.INTERROGATING
        self._notify()
        self._start_timeout()
        await self._motor.set_speed_percent(self._settings.interrogation_speed)

    async def handle_switch_event(self, action: Action, activated: bool) -> None:
        """Called by the switch bank whenever a gearbox switch opens or closes.

        Two events matter, and mode disambiguates them:

        * INTERROGATING + closed + it is the one we want -> gears are in
          position, start the action.
        * ACTING + opened + it is the action we are running + that action has
          a mechanical limit switch (see ACTIONS_WITH_LIMIT_SWITCH) -> the
          limit switch broke the circuit, so the action is finished.

        Everything else is the drum sweeping past, or a switch release from an
        action with no limit switch (its drum switch stays engaged for as
        long as the drum is clutched there, so a release is noise, not
        completion - e.g. TALK, which must keep running for as long as the
        caller wants the mouth moving), and is ignored.
        """
        log.info("switch %s %s", action.value, "closed" if activated else "opened")

        if self._mode is Mode.INTERROGATING and activated and action is self._desired:
            await self._enter_action(action)
        elif (
            self._mode is Mode.ACTING
            and not activated
            and action is self._current
            and action in ACTIONS_WITH_LIMIT_SWITCH
        ):
            log.info("limit switch reached for %s", action)
            await self.request_action(Action.STOP)

    async def _enter_action(self, action: Action) -> None:
        self._cancel_timeout()
        self._current = action
        self._desired = None
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

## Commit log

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2026-08-12 feat: interrogation/action state machine
    Performing an action means running the motor anti-clockwise until the matching
    cam switch closes, then reversing. Intermediate switches are filtered by mode.
    A redundant-STOP guard only applies once the drum is known to be parked at the
    stop position; at boot the position is unknown, so the first stop homes it.
    [controller.py, test_controller.py]
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2026-08-12 feat: espeak-ng speech output
    Serialised under a lock so overlapping requests do not garble each other on a
    single sound card. A missing espeak-ng is logged, not raised.
    [speech.py, test_speech.py]
2026-08-12 feat: entrypoint, lifespan wiring and mDNS advertisement
    Fixes two bugs carried by the original project's zeroconf code: it passed a
    raw IP where mDNS expects a .local. hostname, and could raise UnboundLocalError
    on the failure path.
    build_hardware/build_keypad return fakes unless VERBOT_USE_REAL_HARDWARE is
    set, so the server runs end-to-end on a dev machine.
    [__main__.py, discovery.py, main_support.py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]
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2026-08-15 docs: implementation plan for the KiCad wiring schematic
    Nine tasks, each gated on kicad-cli ERC reporting zero errors and zero
    warnings. Approach validated by spike first: hand-written KiCad 10
    schematics parse, pass ERC clean, and export to PDF/SVG, provided every
    coordinate lands on the 1.27mm grid, power nets carry PWR_FLAG, and
    no-connect flags sit exactly on pins.
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2026-08-15 feat(hardware): sheet generator and power tree
    Places the Pi header, OnOff SHIM, and USB power input, and wires the
    5V/3V3/GND power tree between them. Establishes the sym()/wire()/label()/
    nc()/text_note()/stub_label() helper contract that Tasks 4-8 build on.
    Two fixes versus the literal brief text, both required to get ERC clean:
    - lib_symbols cache join used "\\n" (literal backslash-n) instead of a
    real newline, corrupting the s-expression stream so the file failed to
    parse. Switched to "\n".join(...).
    - The stock USB_B_Micro symbol types its GND pin (5) as a power output,
    not passive. Adding a PWR_FLAG on the GND net as well triggered a
    pin_to_pin "two power outputs" ERC confli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
    [verbot.kicad_sch]
2026-08-15 fix(plan): escaped newlines in generator text_note strings
    The plan's code blocks carried '\\n', which produces a literal backslash-n
    in the Python string and prints as "\n" on the schematic sheet instead of
    breaking the line. Task 3's implementer caught it; fixing at source so the
    briefs for Tasks 4-8 are correct.
2026-08-15 fix(plan): correct newline escaping and sync Task 3 to what was built
    The previous commit over-applied a fix. Only the lib_cache join needed a
    real newline; text_note bodies must keep the literal \n escape, because a
    raw newline inside a quoted S-expression string makes the file
    unparseable (verified: kicad-cli reports "Failed to load schematic").
    Added that rule to Global Constraints so Tasks 4-8 cannot hit it.
    Also synced Task 3's code block to the committed generator: no GND
    PWR_FLAG (USB_B_Micro pin 5 is typed power_out and already drives the
    net), plus the USB data/ID/shield no-connects.
2026-08-15 feat(hardware): DRV8833 motor section
    Wires the DRV8833 carrier to the Pi (IN1/IN2/EEP/ULT on BCM12/13/6/16)
    and to the Verbot motor, per src/verbot/config.py and docs/hardware.md.
    Channel B is left no-connected. Motor_DC is sourced from the Motor
    library rather than Device, where it doesn't exist on this system's
    symbol set; its pin numbers match what the plan assumed.
    [verbot.kicad_sch]
2026-08-15 fix(plan): Motor_DC lives in the Motor library, not Device
    Task 4's implementer hit this: sym("Device", "Motor_DC", ...) does not
    resolve on KiCad 10. Pin numbers 1/2 were as assumed.
2026-08-15 feat(hardware): interrogation switch bank and limit switches
    [verbot.kicad_sch]
2026-08-15 feat(hardware): MAX98357A audio section
    [verbot.kicad_sch]
2026-08-15 feat(hardware): MCP23017 front panel, keypad and status LED
    Wires an MCP23017 I2C expander (0x20, matching Settings.mcp23017_address)
    to the Pi's I2C1 bus and, from it, the eight original front-panel buttons
    (GPA0-7, order per BUTTON_ORDER in hardware/mcp23017.py) and a status LED
    on GPB0. INTA/INTB and GPB1-7 are no-connect, matching the polling driver
    and Mcp23017Led's IODIRB configuration.
    Corrects the LED wiring versus the plan's assumed pin numbering:
    pin_positions() shows Device:LED pin 1 is K (cathode) and pin 2 is A
    (anode), the reverse of what was assumed, so the driven net is wired to
    pin 2 and GND to pin 1 to avoid reverse-biasing the LED.
    [verbot.kicad_sch]
2026-08-15 fix(plan): LED anode/cathode were reversed
    Device:LED pin 1 is K (cathode), pin 2 is A (anode) - the plan had the
    driven net on the cathode and GND on the anode, which would have lit
    nothing and looked like a dead status LED at bring-up. Task 7's
    implementer caught it against pin_positions() rather than copying the
    brief.
2026-08-15 feat(hardware): no-connect unused header pins, ERC clean
    [verbot.kicad_sch]
2026-08-15 feat(hardware): KiCad wiring schematic with PDF/SVG exports
    Export the schematic to PDF and SVG, and link them from docs/hardware.md
    and README.md.
    Fixed several layout bugs found by actually rendering the sheet: net
    labels used a vertical text anchor that collided with each pin's own
    name text on every claimed Pi header pin; several stub directions were
    chosen per net-group without checking which physical side each pin
    landed on, driving the stub back into the header body instead of away
    from it; and a handful of blocks (USB connector, button column, front
    panel notes) sat close enough to each other or the sheet edge that
    their labels overlapped or ran off the page. All coordinate changes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
    [verbot.kicad_sch]
2026-08-15 fix(hardware): take symbol text positions from the library
    The schematic generator hard-coded Reference to (x, y - 2.54) and Value to
    (x, y + 2.54) - offsets from the symbol origin. On a symbol tens of
    millimetres tall those land inside the body: M1's "Pimoroni OnOff SHIM"
    printed across its own POWEROFF pin name and J2's reference sat on the USB
    graphic. Read each library's own Reference/Value offsets instead; every
    symbol used here already places them clear of its body.
    Also move three symbols. M3's value ran off the right edge of the sheet and
    was clipped, so the motor moves left. M6's left-side stub labels and the
    button column's rightward GND labels printed through each other, so the
    e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
    [verbot.kicad_sch]
2026-08-15 fix: VERBOT_MOTOR_SLEEP_PIN=null crashes instead of disabling the pin
    pydantic-settings never JSON-decodes env strings for int | None fields
    unless told to, so "null" hit int_parsing instead of becoming None. Docs
    and the schematic's MOTOR note already told users to set it to null when
    the DRV8833 carrier's J1 jumper is bridged; env_parse_none_str="null" on
    Settings.model_config makes that actually work. Covers motor_fault_pin
    the same way.
    [config.py, test_config.py]
2026-08-15 fix: schematic notes underspecify power pins and keypad polling
    POWER note didn't say which of the twelve stacked +5V/+3V3/GND stubs map
    to which physical header pins - the stock Raspberry_Pi_2_3 symbol prints
    its duplicate power pins on top of each other, so the drawing needs to
    spell out the list the netlist already encodes. FRONT PANEL note left
    the INTA/INTB no-connects unexplained; add the 50 Hz polling rationale
    that previously existed only as a Python comment, matching the design
    spec's requirement.
    Regenerated verbot.kicad_sch and re-exported the PDF/SVG. ERC still 0
    errors, 0 warnings.
    [verbot.kicad_sch]
2026-08-15 docs: link the schematic SVG and add a symbol-regen warning
    GitHub renders SVG inline where it won't render PDF, making it the more
    useful link for reading wiring on a phone at the bench - link it
    alongside the existing PDF link in docs/hardware.md and README.md.
    docs/deployment.md holds the bring-up checklist and wiring
    troubleshooting but linked neither export; point to both from the
    checklist intro.
    Also document that regenerating verbot.kicad_sym with make_symbols.py
    requires a kicad-cli sym upgrade --force pass afterwards - without it
    generate_schematic.py can't read the file's pin blocks and fails with
    KeyError.
2026-08-15 docs: design spec for a token-guarded shutdown endpoint
    Opt-in POST /system/shutdown so the Pi can be powered down cleanly
    without SSH while the OnOff SHIM is missing. The route is not registered
    at all unless a token is configured, so the existing open API surface is
    unchanged for anyone who does not opt in.
2026-08-15 docs: colour wiring map for bench work
    A browser-readable companion to the KiCad schematic. The interrogation
    ribbon is drawn in its actual conductor colours, because on that cable
    the colour IS the identifier - purple is stop, orange is pick up - and
    mapping colour to BCM is the step where a mistake costs an afternoon.
    The two lines carrying arm limit switches are drawn with the switch
    inline, since that is why they can open mid-action.
    Self-contained: no external fonts, scripts or images, and it renders in
    light and dark themes.
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2026-08-16 docs: correct first-boot setup for the cloud-init image variant
    The flashed image is the cloud-init variant of Raspberry Pi OS: bootfs
    carries user-data/meta-data/network-config and cmdline.txt has no
    init=/usr/lib/raspberrypi-sys-mods/firstboot hook. custom.toml is inert
    there, which is why first boot dropped to the user-creation wizard.
    Document both variants and how to tell them apart, and cover the
    instance_id cache that makes cloud-init skip a card that booted once.
2026-08-16 feat: curl-pipeable install script for the Pi
    Automates steps 3-8 of docs/deployment.md: packages, uv, checkout, deps,
    hardware groups, firmware overlays and the systemd unit.
    Idempotent throughout — each step checks its end state, and the config.txt
    append is fenced by markers and backed up first. Refuses to run anywhere
    that is not a 64-bit Raspberry Pi, since armv7l would try to build
    pydantic-core from source and the overlay edit is destructive on anything
    else.
    Enables verbot@USER but does not start it before the reboot: the PWM
    overlay is not loaded until then, so an early start fails on a missing
    pwmchip0 and trips Restart=on-failure.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
2026-08-16 fix: install the lgpio build toolchain
    lgpio publishes aarch64 wheels only up to cp312 and 0.2.2.0 is the latest
    release, so on this image's CPython 3.13 there is no wheel to match and uv
    falls back to the sdist. uv.lock records only the sdist for the same
    reason, so refreshing the lock does not help.
    The sdist runs lgpio.i through swig and links against system liblgpio, so
    the sync died at "command 'swig' failed". Add build-essential,
    python3-dev, swig and liblgpio-dev; all four are present in both Debian
    trixie and the Raspberry Pi archive for arm64.
2026-08-16 feat: speak a readiness greeting when the service starts
    Announces "I am Verbot! How may I help you?" once the controller, keypad,
    LED and mDNS advertiser are all up, so the phrase means the robot is
    genuinely ready rather than merely booting.
    Fire-and-forget: the phrase takes a couple of seconds at speed 130, and
    blocking the lifespan on it would delay /healthz and the panel buttons by
    that much on every restart. The task is cancelled and awaited on shutdown
    so it cannot outlive the app. A speech failure is logged, never raised —
    a robot that will not serve because the sound card is busy is a worse
    failure than a silent one.
    Set VERBOT_STARTUP_ANNOUNCEMENT to change the phrase, or empty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
    [__main__.py, config.py, test_main.py]
2026-08-16 fix: load i2c-dev, and stop double-appending to config.txt
    dtparam=i2c_arm=on brings up the bus but not the /dev/i2c-* character
    devices smbus2 opens; those need the i2c-dev module, which nothing loads
    by default. On the robot /sys/bus/i2c/devices listed i2c-1 while lsmod
    showed only i2c_bcm2835 and /etc/modules was empty. Load it and persist
    it in /etc/modules.
    Also stop appending the firmware block when config.txt already sets
    dtoverlay=pwm-2chan outside our markers. The marker only catches our own
    previous runs, so a copy appended by hand while following step 3 got a
    second copy on top and loaded both overlays twice.
2026-08-16 docs: warn that off-by-one I2S wiring fails silently
    BCLK landed on pin 14 (GND) instead of pin 12 during bring-up and cost an
    afternoon, because nothing reports it. The card registers, aplay lists it,
    pinctrl shows a0 on all three lines and hw_params reads RUNNING with the
    pointer advancing — the Pi clocks valid I2S into a grounded wire.
    Record the three dangerous neighbours, and note that SD_MODE at ~0.45 V on
    the Adafruit board means enabled in mono, so no-sdmode is correct and the
    sdmode variant only costs BCM 4.
2026-08-16 fix: surface espeak failures instead of discarding them
    say() sent stderr to DEVNULL and never checked returncode, so a failing
    espeak-ng was indistinguishable from a successful one. During bring-up
    that meant "spoke", "failed" and "never ran" all produced an identical
    silent log, and audio faults had to be chased with listening tests.
    Capture stderr and log it with the exit code on failure, and log the
    spoken text on success so there is positive confirmation in the journal.
    [speech.py, test_speech.py]
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2026-08-16 fix: wait for udev before writing a freshly exported PWM channel
    _export polled for the channel directory to exist, but the kernel creates
    pwmN root-owned and 99-com.rules chgrps the pwm subsystem to gpio
    asynchronously afterwards. Existence does not imply writability, so the
    first start after a boot raced udev and died with EACCES on duty_cycle.
    Restart=on-failure then succeeded five seconds later, which made a
    deterministic race look like an intermittent fault.
    Poll os.access(..., W_OK) after export, and if it never arrives say so —
    naming the gpio group and the udev rule — rather than surfacing a bare
    PermissionError from pathlib.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
    [pwm_motor.py, test_pwm_motor.py]
2026-08-16 feat: bring-up control page at GET /
    One self-contained HTML page served from the existing app: no build step,
    no static directory to package, no second port. It drives the endpoints
    the API already exposes, so nothing is reachable from the page that is not
    reachable from curl.
    Includes action buttons, an oversized stop, live status polled from
    /status, a speak box, a request/response log, and speed sliders. The
    button list is rendered from the Action enum so a new gearbox position
    cannot appear in the API and go missing from the page.
    Adds GET and PATCH /speeds for the sliders. The controller reads speeds
    off Settings each time it drives the motor, so a change lands on the next
    action. Bo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
    [api.py, test_api.py, web.py]
2026-08-16 fix: the STOP button must halt, not interrogate for the stop cam
    The page bound its oversized red STOP to /stop, which calls
    request_action(STOP) — that drives the drum round looking for the stop cam
    at +interrogation_speed. On a robot with no mechanism attached it ran the
    motor for the full interrogation timeout and then reported FAULT; on a
    real one it moves for seconds before stopping. The opposite of what a
    control labelled STOP should do.
    Controller.halt() already did the right thing and its docstring says so,
    but it had no HTTP route. Add POST /halt and bind the button to it.
    Also restore stop to the action grid. Excluding it conflated two distinct
    operations: halting the motor, an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
    [api.py, test_api.py, web.py]
2026-08-16 feat: optionally animate the mouth while speaking
    POST /say gains an animate flag. When set it interrogates for TALK, waits
    until the gear is actually engaged, speaks, then parks the drum at the stop
    cam. Talk has no limit switch — per docs/hardware.md the gear set runs
    until the motor reverses — so something has to end it explicitly.
    The wait matters: interrogation takes seconds, so starting the phrase when
    the request is accepted would play the audio before the mouth moves. Adds
    Controller.wait_until_acting for that, backed by an event pulsed on every
    mode change rather than polling the status property.
    A mouth that never engages is logged and then ignored, returning
    animated: false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
    [api.py, controller.py, test_api.py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]
2026-08-16 docs: theory of operation
    How the gearbox works, what replaced the original electronics, how the
    software drives it, and the API — in one place, for someone meeting the
    project cold.
    The mechanical section is the load-bearing part: a single motor whose
    direction selects between interrogation and action explains why the
    controller is a state machine, why the watchdog guards only interrogation,
    why halt and stop are different operations, and why most actions have to be
    ended by the operator.
    Includes mermaid diagrams for the layering and the state machine, an
    endpoint table, and the environment variables that change behaviour.
2026-08-16 feat: shutdown control on the web page
    Rendered only when VERBOT_SHUTDOWN_TOKEN is set, since the route does not
    exist otherwise and a button would only ever 404.
    The token is deliberately not served in the page. The page is
    unauthenticated, so embedding it would hand poweroff to anyone on the LAN
    and undo the reason the endpoint is guarded — the design spec calls out
    that remote poweroff is a different proposition from waving the arms
    around. The browser prompts once, keeps it in localStorage, and forgets it
    again on a 401.
    Confirms before firing, and stops the status poll on success so the log
    does not fill with connection failures as the machine goes.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
    [api.py, test_api.py, web.py]
2026-08-17 fix: treat a blank shutdown token as unset, not as a valid credential
    secrets.compare_digest(b"", b"") is True, so shutdown_token="" plus an
    empty X-Verbot-Token header authenticated an unguarded remote poweroff.
    `shutdown_token is not None` let an empty string through; both call
    sites now go through a single Settings.shutdown_enabled property that
    requires a non-blank token, and a blank-but-set token now logs a
    warning instead of silently arming nothing.
    [api.py, config.py, test_api.py]
2026-08-18 fix: stale current_action after halt(), and shutdown-endpoint hardening
    halt() left _current pointing at the previous cam when it interrupted
    INTERROGATING, not ACTING, so request_action's "already parked" shortcut
    skipped a subsequent /stop entirely - reachable both via a failed poweroff
    grant and the web page's emergency STOP followed by the stop button. Clear
    _current only in the INTERROGATING case, where the drum really is between
    cams; keep it in the ACTING case, where it is still accurate.
    Also, from the same review: log a warning (never the token) when a shutdown
    attempt is rejected, strip both sides of the token comparison so a padded
    .env value and a real ASGI server's own header s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
    [api.py, controller.py, system_power.py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]
2026-08-18 docs: fix the shutdown-endpoint walkthrough in deployment.md §9
    Restart the service before the verification curl - the route is registered
    once at startup, so editing .env alone does nothing, and the 404 paragraph
    was misdiagnosing exactly that. Validate the sudoers file with visudo -f
    before it is installed rather than after, since a syntax error is otherwise
    live before it is caught and sudo then refuses to run at all. Prove the
    grant non-destructively with sudo -n -l before the curl that actually powers
    the Pi off, note that a 202 is returned before poweroff is even attempted so
    it isn't proof of success, and chmod 600 the .env holding the token.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
2026-08-18 fix: clear _current when halting from FAULT too
    FAULT is only ever entered from the watchdog firing mid-INTERROGATING, so
    the drum is mid-sweep with an unknown position there exactly as it is in
    INTERROGATING itself - halt() was only clearing _current for the latter.
    Express the rule positively instead of enumerating modes: _current is kept
    only when the drum is stationary at a known cam (ACTING, IDLE), and cleared
    for everything else, so a future mode can't silently inherit stale state.
    [controller.py, test_controller.py]
2026-08-19 docs: explain how the motor is powered
    The docs said "feeding VCC from 5V" without ever saying from where, and
    never separated the signal path from the power path. That leaves the
    reasonable conclusion that the Pi is expected to supply motor current,
    which it cannot.
    Spell out that IN1/IN2/EEP are high-impedance inputs drawing microamps
    while motor current flows VCC -> H-bridge -> OUT1/OUT2 -> GND and never
    touches a GPIO, why the common ground still matters, and why VCC should
    come from the power bank rather than the Pi's 5V header pin — a stalled
    3V motor pulling an amp through header pins and the OnOff SHIM is how the
    rail sags far enough to drop Wi-Fi or reset the board.
    Also records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
2026-09-11 config: raise default interrogation PWM to 90
    50 was too weak to turn the drum reliably; 90 is the new baseline.
    Claude-Session: https://claude.ai/code/session_01D4gPFhUD3UFrTbvGRPmKkJ
    [config.py, test_api.py, test_controller.py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]
2026-09-11 fix: talk action stopping early on a spurious switch release
    handle_switch_event() treated any switch opening while ACTING as the
    mechanical limit switch that ends the action. Per docs/hardware.md only
    pick_up/put_down actually have such a limit switch in series - every
    other action's drum switch stays engaged as long as the drum is
    clutched there, so a release seen for e.g. talk is noise, not
    completion. On real hardware this was stopping the talk motor after a
    fraction of a second instead of letting it run for the whole spoken
    phrase.
    Restrict the auto-stop path to the new ACTIONS_WITH_LIMIT_SWITCH set
    (pick_up, put_down); everything else now runs until an explicit stop
    is requested, whic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
    [actions.py, controller.py]
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2026-09-20 fix: drop the shutdown token, confirm in the browser instead
    The token was the only authenticated endpoint in an otherwise open API
    that already advertises itself over mDNS - friction with no matching
    security benefit. /system/shutdown is now gated by a plain
    VERBOT_SHUTDOWN_ENABLED flag, and the web UI just confirm()s before
    sending the request instead of prompting for and storing a credential.
    [api.py, config.py, test_api.py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]
2026-09-20 fix: back interrogation speed off to 85 to stop cam overshoot
    90 turned the drum reliably but overshot narrow cams before the motor
    finished reversing, landing one switch further round the drum than
    requested (confirmed on hardware: rotate_right/rotate_left were firing
    each other's neighbor, and reducing to 85 fixed it). Update the docs'
    tuning guidance to describe both bounds instead of just the stall floor.
    [config.py, test_api.py, test_controller.py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]
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
